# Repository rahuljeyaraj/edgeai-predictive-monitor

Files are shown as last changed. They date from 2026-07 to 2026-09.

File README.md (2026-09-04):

# EdgeAI Predictive Monitor

### Sensors that watch. An AI that decides. A hand that pulls the plug.

A sensor pod that clips onto a machine, learns what *that* machine's healthy
vibration and sound are, and — when it is confident enough that something is
going wrong — **stops the motor**. Not an email. The motor.

Built on the **Arduino UNO Q**: real-time sampling and FFTs on the STM32U585
side, and on the Qualcomm Dragonwing QRB2210 Linux side, on-device PyTorch
training, an Edge Impulse fault classifier, a live dashboard, an MQTT broker,
and the decision to trip.

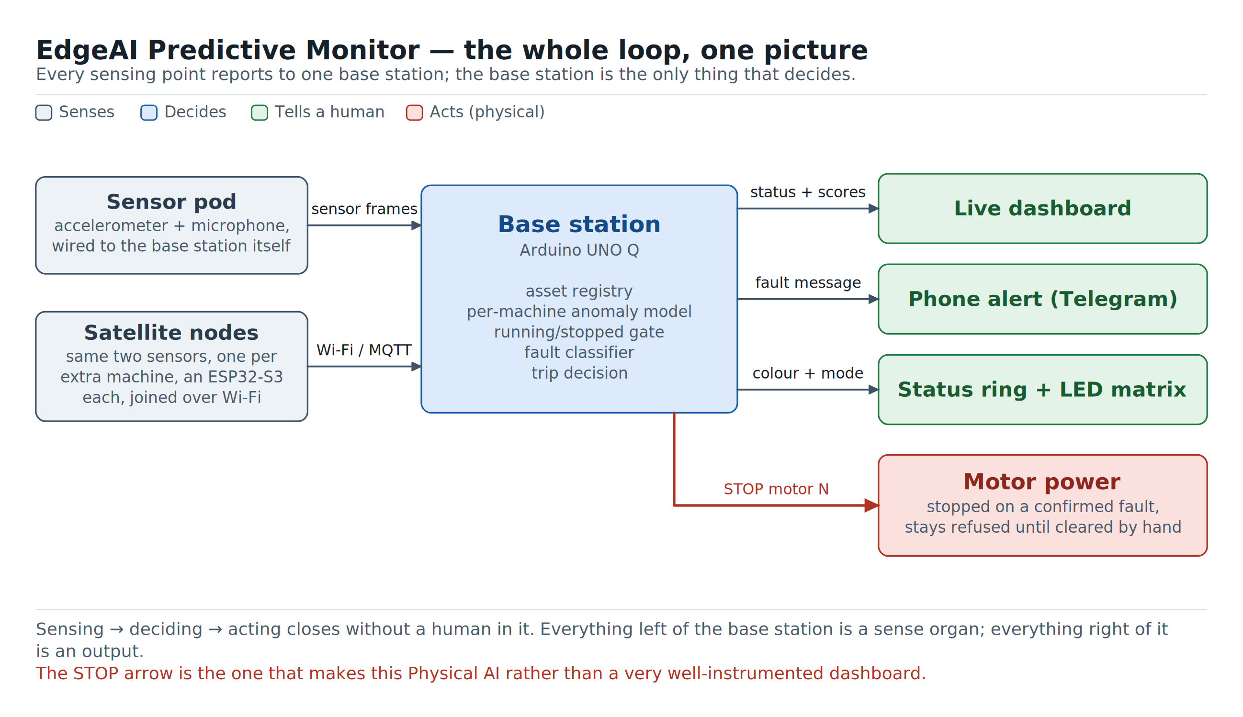
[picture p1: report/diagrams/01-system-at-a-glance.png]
System at a glance


---

## Start here

**[📄 Read the full report →](report/REPORT.md)** — the design, the measured
results, the dead ends, the bill of materials, the schematics, and a
command-by-command build guide. It stands on its own; everything below is a
shortcut into it.

| I want to… | Go to |
|---|---|
| See it running, **with no hardware at all** | [Report → Appendix C.1](report/REPORT.md#appendix-c-build-one-yourself) — 10 minutes, one script |
| Understand what it does and why | [Report → Chapter 1](report/REPORT.md#chapter-1-the-machine-that-never-complains-until-its-too-late) |
| See the part that makes it *Physical AI* | [Report → Chapter 8](report/REPORT.md#chapter-8-the-day-it-stopped-itself) |
| Buy the parts | [Report → Appendix A](report/REPORT.md#appendix-a-bill-of-materials) — ≈ ₹8,115 for one machine |
| Wire it up | [Report → Appendix B](report/REPORT.md#appendix-b-wiring-and-pinout-reference) + [`hardware/kicad/`](hardware/kicad/) |
| Read the code | [Report → Appendix L](report/REPORT.md#appendix-l-reading-the-source) |

## Try it without buying anything

Runs the **real** dashboard on your laptop, fed by a simulator speaking the
**real** wire protocol, replaying **real** captured sensor data. Not a mock —
the registry, feature pipeline, autoencoder, setup flow, thresholds and
classifier are the same code that runs on the board.

```sh
sudo apt-get install -y mosquitto mosquitto-clients   # broker on :1883
sudo systemctl enable --now mosquitto

cd base-station
./start_desktop_dashboard.sh
```

It prints two URLs: the dashboard, and the simulated node's own control page.

## What it does

- **Learns each machine individually.** A short guided setup — name it, measure
  it switched off, run it, train — and that machine has its own model and its
  own thresholds. Training happens on the UNO Q, in seconds. No cloud.
- **Knows when a machine is simply off.** A running/stopped gate calibrated
  against each sensor's own measured noise floor, which turned out to be the
  hardest measurement in the project.
- **Names the fault.** A second model, trained in Edge Impulse and run on-device
  as TFLite, says *bearing* / *imbalance* / *loose mount* — one model per
  machine *type*, so five identical lathes share one.
- **Stops the motor.** On a sustained fault: a visible ten-second countdown with
  a Hold button, then a per-motor stop that latches until a human clears it. If
  the machine keeps turning, it reports the trip as **failed** rather than
  claiming success.
- **Tells someone.** A status ring on the machine, the board's own LED matrix,
  a five-tab live dashboard, and a Telegram alert.
- **Scales over Wi-Fi.** Satellite nodes (XIAO ESP32-S3) join by captive portal
  from a phone — no app, no recompile, no ID to type.

## Repository map

| Path | What's in it |
|---|---|
| [`base-station/`](base-station/) | The UNO Q: Zephyr firmware (`sketch/`), the Linux application (`python/`), host bridges (`host/`), 34 test modules (`tests/`) |
| [`satellite/`](satellite/) | XIAO ESP32-S3 wireless sensor node (PlatformIO) |
| [`motor-driver/`](motor-driver/) | The validation rig: Arduino Uno + CNC Shield firmware, the rig host, and its control page |
| [`hardware/kicad/`](hardware/kicad/) | Three real KiCad schematics, generated from Python |
| [`report/`](report/) | The full report and the generators for every diagram in it |
| [`3d-models/`](3d-models/) | Thirteen printable parts: node enclosures and the validation rig, as 3MF and STL |
| [`docs/BILL_OF_MATERIALS.md`](docs/BILL_OF_MATERIALS.md) | The canonical parts list: what to buy, per build scale, with links |
| [`docs/BUILD_GUIDE.md`](docs/BUILD_GUIDE.md) | Build one yourself, from printed shell to a commissioned machine |
| [`docs/`](docs/) | Design plans and investigation records — the long-form version of the report's appendices |

## Status

| | |
|---|---|
| Sensing, guided setup, per-machine anomaly model | Live-verified on hardware |
| Running/stopped gate with measured baseline | Live-verified on hardware |
| Physical motor trip: stop + latch + confirm | Live-verified on hardware, both directions |
| Dashboard, status ring, LED matrix, Wi-Fi onboarding | Live-verified on hardware |
| Edge Impulse classifier, on-device | Built; trained on 541 real captures from this rig |
| Satellite nodes | Built |
| Telegram alerts | Built and demonstrated; off pending one config value |
| Per-motor relay (cutting power, not just motion) | Not built |

The report's [Chapter 12](report/REPORT.md#chapter-12-proof-not-promises) has
every measured number, and
[Appendix J](report/REPORT.md#appendix-j-test-suite-and-verification-record)
records how each was checked.

## Safety

This is a condition-monitoring system with a protective trip. **It is not a
certified functional-safety system** and must not be used as a guard interlock —
it has no safety integrity level, no redundant channel, and if the base station
loses power nothing trips. It stops *motion*, not power. Every safety function a
machine already has stays exactly where it is. See
[Report → §8.4](report/REPORT.md#chapter-8-the-day-it-stopped-itself).

## Built for

- **Arduino Physical AI Challenge India 2026** — Industrial & Sustainability AI
- **Invent the Future with Arduino UNO Q and App Lab** (Hackster.io) —
  Industrial IoT

## Licence

[MIT](LICENSE).

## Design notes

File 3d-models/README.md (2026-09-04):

# 3D-printed parts

Thirteen printable parts, each supplied as both **3MF** (plated and ready to
slice, with the colour already assigned) and **STL** (plain mesh, if you would
rather plate it yourself).

Print the 3MF unless you have a reason not to. The plates are already oriented
so nothing needs supports.

File names encode the assembly and the filament colour: `a` is the base station,
`b` is the satellite, `c` is the validation rig.

| File | Contains | Colour | Needed for |
|---|---|---|---|
| `a1_base_station_silver` | Shell, `main_front` + `main_back`, snap-fit halves with a front panel cutout | Silver | Base station |
| `a2_base_station_silver` | Mount kit: `left_plate` + `right_plate` backplates, a standoff `leg`, two `stem_connector` pieces joining leg to plate | Silver | Base station |
| `a3_base_station_orange` | Front bezel: `left_rim` + `right_rim` framing the **lens insert** over the status window, plus a separate `foot` standoff | Orange | Base station |
| `b1_satellite_silver` | Shell, same two-piece pattern as `a1`, scaled down for the XIAO ESP32-S3 pod | Silver | Each satellite |
| `b2_satellite_silver` | Mount kit, same as `a2`, scaled for the satellite shell | Silver | Each satellite |
| `b3_satellite_orange` | Front bezel: `left_rim` + `right_rim` plus `foot`. **No lens insert**, since a satellite has no LED matrix | Orange | Each satellite |
| `c1_belt_drive_rig_grey` | Upright L-bracket (`bracket_main`) with a large bearing bore and base mounting holes | Grey | Belt-drive rig |
| `c2_belt_drive_rig_gold` | Three retaining rings: `bearing_ring_1`, `bearing_ring_2`, and an oblong `stepper_ring` | Gold | Belt-drive rig |
| `c3_belt_drive_rig_gold` | Toothed pulley with hex bore, matching hex shaft with pin holes, and a `bearing_holder` hub coupler | Gold | Belt-drive rig |
| `c6_direct_drive_rig_grey` | U-shaped pillow-block `bracket` with a large bearing bore, mounting holes on base and side | Grey | Direct-drive rig |
| `c7_direct_drive_rig_gold` | `bearing_ring_1`, `bearing_ring_2`, `stepper_ring` and the coupling shaft | Gold | Direct-drive rig |
| `c4_fly_wheel_grey` | Rotor disc (`fly_wheel`) with hex hub and a bolt circle | Grey | **Both** rigs |
| `c5_fly_wheel_ring_gold` | Bolt-on ring (`fly_wheel_ring_1`) matching the flywheel's hole pattern | Gold | **Both** rigs |

## What you actually need to print

- **One base station:** `a1`, `a2`, `a3`
- **Each satellite node:** `b1`, `b2`, `b3`
- **Nothing else is needed for a deployment.** The `c` parts are the validation
  rig used to induce and measure faults on the bench.
- **One rig:** pick belt-drive (`c1`, `c2`, `c3`) or direct-drive (`c6`, `c7`),
  then add the shared flywheel (`c4`, `c5`) either way.

## Print settings

| | |
|---|---|
| Material | PLA+ |
| Nozzle | 0.4 mm |
| Layer height | 0.2 mm |
| Infill | 20% for shells and bezels, 40% or more for rig brackets and the flywheel |
| Supports | none; the plates are already oriented |

Colours are what this build used, not a requirement. Any PLA works.

## The flywheel is the fault injector

`c4` + `c5` carry a bolt circle taking M6 × 18 mm bolts. Adding, removing or
moving bolts around that circle produces a repeatable, measurable imbalance,
which is how the labelled fault recordings behind the classifier were made.

## Optional: the embossed wordmark

[`hardware/enclosure-logo/`](../hardware/enclosure-logo/) has emboss-ready SVGs
for the shell faces, sized for the base station and the satellite separately,
with its own README on slicer settings. Engrave recessed at 0.3 to 0.4 mm, not
raised.

Assembly order is in [`docs/BUILD_GUIDE.md`](../docs/BUILD_GUIDE.md); the parts
that go inside these shells are in
[`docs/BILL_OF_MATERIALS.md`](../docs/BILL_OF_MATERIALS.md).

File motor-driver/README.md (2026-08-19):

# Motor Driver: the rotating machine under test

Arduino firmware + browser control page + a host-side rig controller. The Uno
is wired for three stepper motors, but **the rig starts with one installed**,
and the rest are added on the control page — which is the same order a real
factory grows in:

1. A factory sets up its first motor with its own control page —
   `dashboard.html` here, talking straight to the Uno over serial. No AI, no
   base station, no dependency on anything else in this repo.
2. Predictive monitoring gets added later, completely decoupled: the MPU
   vibration sensor watches the motor, but nothing about motor *control*
   changes. The motor's card gains a **PROTECTED** badge naming the asset
   that watches it.
3. More motors are added on the control page as the floor grows. Each one
   installed is announced to the base station as a trip output, so it can be
   mapped to a monitored asset without touching a config file — see
   [../docs/MOTOR_STOP_PLAN.md](../docs/MOTOR_STOP_PLAN.md). That coupling is
   one-way: the base station can stop a motor, never start one.

Design rationale and the capture speed profile live in
[../docs/motor-driver.md](../docs/motor-driver.md).

## Contents
- `src/main.cpp` — Arduino Uno firmware (PlatformIO project, needs
  AccelStepper). Deliberately simple: it applies whatever RPM it's told
  immediately, no ramp logic on the device — see "Why the firmware has no
  ramp" below.
- `dashboard.html` — browser control page: one card per installed motor
  (slider + type-in speed, on/off, sync) over Web Serial. Ramping lives here.
- `motor_driver.py` — the **rig host**. Serves the control page, listens for
  protection trips over MQTT, and can run a scripted capture profile. It does
  *not* hold the Uno's serial port by default — the control page does.
- `start_motor_driver.sh` — starts the rig host (use this, not
  `python3 -m http.server`).
- `fake_uno.py` — runs the rig host against a pseudo-terminal, so the control
  page can be clicked through with no hardware at all.
- `rig_trip_test.py`, `control_page_test.py` — tests; see below.

## Hardware
Arduino Uno + CNC Shield V3 + 3× A4988/DRV8825 drivers in the **X, Y, and Z**
slots. Single 12–24 V supply into the shield terminal.

| Signal  | Motor 1 (X) | Motor 2 (Y) | Motor 3 (Z) | Notes |
|---|---|---|---|---|
| STEP | D2 | D3 | D4 | |
| DIR | D5 | D6 | D7 | |
| ~ENABLE | D8 | D8 | D8 | shared, active LOW |

> **There is no per-motor enable.** One `~ENABLE` line feeds all three driver
> sockets, so `e`/`d` energize or coast *everything*. Stopping a single motor
> means commanding it to 0 RPM. This matters: `e` re-applies whatever speed
> each motor was last told, so anything that stops a motor must send `N 0`
> for it — sending only `d` leaves a stale speed armed, and the next `e`
> (triggered by starting some *other* motor) will spin it back up.

> Set each driver's **Vref (current limit)** before running, and never
> insert/remove a driver with power applied. See the docs file for details.

## Why the firmware has no ramp
Re-flashing this Uno means connecting through WSL, uploading, then
disconnecting again to test over serial — slow enough that firmware changes
should be rare. So `src/main.cpp` only does the minimum: parse a command, set
a motor's speed immediately (`setSpeed()`/`runSpeed()`, no acceleration
curve). Jumping straight to a high RPM can stall a motor, so **all ramping
happens on the host** — `dashboard.html` and `motor_driver.py` both walk the
commanded speed toward the target in small steps before sending it. Tuning or
fixing ramp behavior is now a dashboard/script edit, not a re-upload.

## Build & upload (PlatformIO)
```bash
cd motor-driver
pio run                 # compile-check
pio run -t upload       # flash the Uno (pick the right --upload-port if prompted)
pio device monitor -b 115200   # optional: watch the serial console
```
Confirm `MICROSTEP` in `src/main.cpp` matches the **MSx jumpers** on the
shield (default `1` = no jumpers = full step) before uploading.

## Serial control (115200 baud, newline-terminated)
| Command | Effect | Replies |
|---|---|---|
| `1 <rpm>` | set motor 1 speed (RPM), applied immediately  | silent  |
| `2 <rpm>` | set motor 2 speed (RPM), applied immediately  | silent  |
| `3 <rpm>` | set motor 3 speed (RPM), applied immediately  | silent  |
| `b <rpm>` | set ALL THREE motors, applied immediately | silent  |
| `e` / `d` | energize / coast **all three** drivers | status  |
| `s` | print status | status  |
| `h` | print help | help |

Speed commands answer with nothing on purpose. A status line overflows the
Uno's 64-byte serial TX buffer, which makes `Serial.print()` block and stalls
the step-pulse loop for *all three* motors — during a host ramp that's ~30
stalls/second, and it was audible as every motor stuttering whenever any one
of them changed speed. Poll `s` when you want state.

Negative RPM reverses direction; RPM is clamped to ±1200 (full step).

Example (Arduino Serial Monitor or any terminal) — note the firmware won't
ramp for you, so jumping straight to a high RPM this way can stall a motor:
```
1 60        # motor 1 to 60 RPM (small enough to not need a ramp)
d           # coast to silence
```
For anything faster or bigger, use the dashboard or `motor_driver.py` instead —
they do the ramping.

## Running the rig
```bash
cd motor-driver
./start_motor_driver.sh                          # everything defaulted
./start_motor_driver.sh --mqtt-host uno-q.local  # broker at a different host
./start_motor_driver.sh --mqtt-host ''           # no broker at all
```

Nothing needs to be typed in the normal case. The broker defaults to
`epm-base.local` (the base station's LAN hostname), port **1883**.

> Watch for `ANNOUNCED outputs [1] on epm/motor_rig/outputs`. If the broker
> can't be reached, the rig says so after 6 seconds and tells you nothing was
> announced — because a silent non-connection leaves the base station showing
> whatever a *previous* run left retained, which looks exactly like a bug in
> the dashboard and isn't one.

> After a reboot or a replug, run [`../after_reboot.sh`](../after_reboot.sh)
> first. adb port forwards and the base station's container do not come back
> on their own, and every symptom of that looks like a network fault.

Then open **http://localhost:8000/** in desktop **Chrome or Edge** (Web Serial
isn't supported in Firefox/Safari, or inside sandboxed iframes), click
**Connect**, and pick the Uno's port.

### Who holds the serial port
By default **the control page does**, over Web Serial — and the rig host never
opens it. That is the only arrangement that works on the usual split setup:

> The rig host runs in **WSL**. Chrome and the Uno are on **Windows**.
> `usbipd`-forwarding the Uno into WSL doesn't fix it, it just moves the
> problem — Windows then loses the device and the page has nothing to
> **Connect** to.

So the rig host does the network half (serves the page, holds MQTT, records
trips) and the page does the motor half. When a trip arrives, the rig host
records it and **the page sends the stop**. The header shows `trip via this
page` while that's the arrangement, and turns red with `— not connected` when
the page isn't attached to a port, because protection genuinely is off then.

Pass `--port /dev/ttyACM0` (or `--port auto`) to have the rig host hold the
port instead — for browser-less protection, or a scripted run. `--port auto`
never picks the UNO Q base station, which is also an Arduino-VID device on
`/dev/ttyACM*`; that would write stepper commands into the monitoring board.

`start_motor_driver.sh` passes every argument through to `motor_driver.py`
(`--help` for the full list). It uses `./.venv/bin/python` when that exists,
because `pyserial`/`paho-mqtt` can't be installed system-wide on a PEP 668
host:

```bash
python3 -m venv .venv && ./.venv/bin/pip install pyserial paho-mqtt
```

> **Don't serve this page with `python3 -m http.server`.** It works — you can
> still drive motors — but the page then has nobody to ask which motors are
> installed or whether one has been tripped, and it says so in a banner.

### Motor cards
Each motor card has two independent controls:

- **Speed** — the RPM setting (slider or type-in). Stopping a motor never
  changes this, so starting it again ramps back to the same speed.
- **Run / Stop** — whether that speed is currently applied.

The card also shows a RUNNING/IDLE/STOPPED pill and the currently-commanded
RPM as it ramps toward the setting. **Sync** makes the other motors follow the
first one, and only appears once there are two; changing a follower directly
turns Sync back off. **Stop All** stops everything immediately, skipping the
ramp, and preserves the speed settings.

> Because `~ENABLE` is shared, the page only de-energizes once **all** motors
> are stopped, and it always commands a stopped motor to 0 RPM rather than
> relying on `d`.

> The port opens with a ~2 s Uno reset; wait for the `=== motor-driver ready
> ===` line in the console before driving.

### Adding and removing motors
The rig starts with **one** motor (`--motors` sets the startup set). The empty
slots are `+ Add Motor N` — clicking one installs that motor *and* re-announces
the rig's trip outputs over MQTT, so the new output appears in the base
station's setup live, with nothing restarted. `✕` removes a motor again
(disabled while it's running).

This is the one thing the rig host exists for that a static file server can't
do: the control page has no MQTT client, and the broker is TCP-only, so the
page posts to `motor_driver.py` and *it* publishes the announce.

### Protection status
With `--mqtt-host` set, the page also reads the base station's
`GET /trip_outputs` directly (its API sends `Access-Control-Allow-Origin: *`).
A motor the base station has claimed shows a **PROTECTED · &lt;asset&gt;** badge,
and the header counts how many are protected. Point it elsewhere with
`--base-station-url`; the default is `http://<mqtt-host>:8080`.

### When a trip lands
A trip turns the motor's card red, sets the pill to **TRIPPED**, locks the run
switch, and names the asset that faulted. Only **Reset & re-arm** brings it
back — a trip is sticky until a human clears it, enforced in
`Rig.motor()` and not merely promised.

## Scripted capture runs
```bash
./start_motor_driver.sh --profile --motors 1,2,3   # needs the port; autodetects it
```
Runs baseline → speed sweep → injected fault (the first installed motor steps
up, the rest are held) so the captured vibration maps to labels, then exits.
Without `--profile` the rig host just idles with the control page served and
the trip listener armed.

> Don't expect to observe a live trip during `--profile`: its fixed timing
> races the base station's variable fault-detection timing, and the profile
> has ended before the trip lands (`docs/progress4.md`).

## Tests
```bash
python3 rig_trip_test.py                                   # no hardware needed
../base-station/python/.venv/bin/python control_page_test.py   # needs playwright
```
`rig_trip_test.py` pins the trip's exact serial bytes and the runtime-editable
output set. `control_page_test.py` drives `dashboard.html` in a real headless
Chromium against a real `ControlServer` and a stand-in base station.

## Clicking through it with no hardware
`fake_uno.py` runs the rig host against a pseudo-terminal instead of a real
Uno. Everything except the motors is real — same page, same control server,
same MQTT trip listener:

```bash
python3 fake_uno.py                        # open http://localhost:8000/
python3 fake_uno.py --mqtt-host <uno-q>    # against a real base station
python3 fake_uno.py --mqtt-host <uno-q> --trip-after 20   # trip motor 1 at 20 s
```

`--trip-after` publishes the base station's exact `MOTOR_STOP` bytes, so the
trip arrives through the real listener — the way to see the tripped card and
**Reset & re-arm** without waiting for a genuine fault. Web Serial will fail
to find a port; ignore it, none of the above needs it.

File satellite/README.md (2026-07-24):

# satellite — ESP32S3 satellite node firmware

PlatformIO/Arduino firmware for the Seeed Studio XIAO ESP32S3, one of
potentially several **satellite** vibration/audio sensing nodes for the
EdgeAI Predictive Monitor. It ports [`base-station/sketch`](../base-station/sketch)
(the Zephyr firmware for the UNO Q's onboard STM32U585) to this board,
mirroring every functional piece — KX134 accelerometer, INMP441 I2S
microphone, WS2812 status ring, per-channel FFT, fused publish cadence —
except the transport: the base station talks SPI to its MPU over a wired
point-to-point link; this node talks WiFi + MQTT instead, since it isn't
physically attached to the UNO Q
([docs/SENSOR_TELEMETRY_FRAME_PLAN.md](../docs/SENSOR_TELEMETRY_FRAME_PLAN.md)
S6).

There is no LED matrix on this node (no MQTT command type exists for one,
and the existing satellite tooling doesn't model one either — see
[`python/tools/satellite_node_sim.py`](../base-station/python/tools/satellite_node_sim.py)).

## Wire format

Telemetry (`epm/<node_id>/data`) is the **same generic section-list frame**
the base station's own SPI link sends
([`base-station/telemetry_schema.json`](../base-station/telemetry_schema.json),
[docs/SENSOR_TELEMETRY_FRAME_PLAN.md](../docs/SENSOR_TELEMETRY_FRAME_PLAN.md)
S3/S6): `[num_sections u8]` then, per channel, a
`[source_id][channel_id][data_kind][section_len]` header followed by either
a SPECTRUM body (`fs`/`fft_size`/`bin_count`/dense float32 bins) or, for one
trailing SCALAR_SET section, a `count`/id-array/value-array body. Published
as the raw MQTT message body with **no extra envelope** — MQTT already
frames and delivers each message, so a second TYPE byte would be redundant.
This node emits one SPECTRUM section per enabled per-axis channel (`mic`,
`accel_x`, `accel_y`, `accel_z` — the combined `accel` channel was retired
once the base station's own model moved to per-axis, see
`pipeline/features.py`) plus one SCALAR_SET section carrying that same
channel set's `rms`/`kurtosis`/`std`/`peak`/`crest_factor`/`skewness` tiles
(`frame_codec/spectrum_codec.h`, `struct spectrum_channel`/`struct
scalar_entry` + `telemetry_build_frame()`) — `pipeline/features.py`'s
`build_feature_vector()` rejects a frame outright if any live channel is
missing its full 6-scalar tile. Wire constants (`TELEM_SOURCE_SATELLITE`, `TELEM_CHANNEL_MIC`, …)
live in `include/frame_codec/telemetry_schema.h`, generated (not hand-edited)
by
[`python/tools/gen_telemetry_schema.py`](../base-station/python/tools/gen_telemetry_schema.py)
from the same schema file the base station and MPU parser are generated
from, so the three sides can't drift. This replaced an earlier fixed
`spectrum_fused_payload_header` struct (itself replacing a still-earlier
JSON envelope of top-N peaks per channel) once the base station's own wire
format moved to this generic section-list shape.

The command direction (`epm/<node_id>/cmd`, STATUS_LED) keeps its own lean
`[TYPE: 1B][display_rgb_payload]` envelope (`frame_codec/wire_protocol.h`) —
unaffected by the telemetry-format change above.

The wire shape matches
[`python/tools/satellite_node_sim.py`](../base-station/python/tools/satellite_node_sim.py)
and
[`python/ingestion/mqtt_subscriber.py`](../base-station/python/ingestion/mqtt_subscriber.py)
field-for-field, so a real node and the simulator are interchangeable from
the dashboard's point of view. FFT window sizes (1024 per channel → 512
native bins, pooled to `MODEL_SPECTRUM_BINS` = 128 for the wire — a node's
actual per-channel bin count is committed dynamically from its first frame
by
[`python/pipeline/manager.py`](../base-station/python/pipeline/manager.py),
not a fixed global table) and the publish cadence (200ms) are set in
`include/app_config.h`.

## Hardware / wiring

XIAO ESP32S3 breaks out 11 GPIOs (D0–D10). Full pin rationale is in
`include/board_pins.h`; summary:

| Signal | Pin | Notes |
|---|---|---|
| KX134 SPI SCK | D8 | hardware SPI default |
| KX134 SPI MISO | D9 | hardware SPI default |
| KX134 SPI MOSI | D10 | hardware SPI default |
| KX134 CS | D3 | software chip-select |
| KX134 INT1 (BFI) | D2 | buffer-full interrupt |
| INMP441 WS/LRCLK | D0 | |
| INMP441 BCLK | D1 | |
| INMP441 SD (data in) | D4 | |
| WS2812 ring DIN | D5 | 8-pixel ring, same product as the base station's |

`LED_BUILTIN` (GPIO21, onboard) is the heartbeat indicator — independent
of the WS2812 ring, mirroring the base station sketch's own onboard-LED
heartbeat.

## Configuration

WiFi/MQTT settings live in `include/app_config.h` as overridable
`#define`s (`WIFI_SSID`, `WIFI_PASSWORD`, `MQTT_BROKER_HOST`,
`MQTT_BROKER_PORT`). Defaults assume the base station hosts its own AP
(SSID `EPM-BaseStation`) and runs the Mosquitto broker at `10.42.0.1` —
confirm these against the actual base-station deployment before flashing.
**`WIFI_PASSWORD` has no documented value and must be set before
flashing**, either by editing `app_config.h` directly or overriding via
`platformio.ini`'s `build_flags` (`-D WIFI_PASSWORD=\"...\"`).

Node identity is derived automatically from the ESP32's WiFi MAC address
(last 6 hex chars, lowercase) — no per-device flashing-time configuration.

## Build / flash

```sh
cd satellite
pio run                # build
pio run -t upload      # flash over USB (native USB CDC, no separate bridge chip)
pio device monitor     # serial log console (115200 baud)
```

After editing `base-station/telemetry_schema.json`, regenerate every
generated side (including this firmware's
`include/frame_codec/telemetry_schema.h`) with:

```sh
python3 base-station/python/tools/gen_telemetry_schema.py
```

## What's *not* hardware-verified

Everything in `base-station/sketch` was brought up and tuned against real
STM32U585 hardware (documented empirically in that codebase's comments —
e.g. the KX134 SPI pin-routing finding, the I2S DMA-width bug). This port
compiles clean (`pio run`, zero warnings under `-Wall -Wextra`) but **has
not been run against a physical XIAO ESP32S3 + KX134 + INMP441 + WS2812
ring**. Specifically flagged as assumptions, not findings, in the source
comments:

- `src/drivers/mic_i2s.cpp`: sample rate (48kHz) and the INMP441's
  32-bit-slot right-shift (`>> 8`) — reasonable per-datasheet defaults,
  not bench-confirmed.
- `src/threads/accel_sampler_task.cpp`: `ACCEL_SAMPLER_READ_CHUNK_FRAMES`
  (64) — carried over from the base station sketch's own tuned result, not
  re-derived from a characterization run on this board.
- `include/board_pins.h`: the D0–D5 assignments are conflict-free on
  paper (verified against the XIAO ESP32S3 variant's actual
  `pins_arduino.h`) but unverified against a real wiring harness.

Bring-up on real hardware should revisit these the same way
`base-station/sketch`'s own comments document its STM32 tuning history.
The telemetry wire format itself (this doc's "Wire format" section) is
verified by construction — generated from the same schema the base
station and MPU parser share — but has not yet been exercised by a real
publish against a running `mqtt_subscriber.py`; do that once hardware is
available, the same way `satellite_node_sim.py` already exercises it in
simulation.

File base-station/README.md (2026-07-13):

# 📳 edgeai-predictive-monitor-base-station

On-device predictive maintenance for rotating machinery

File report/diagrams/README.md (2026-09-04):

# Report diagrams

Block diagrams for `REPORT.md`. No graphviz or mermaid on this machine, so
they're composed in plain Python and rasterised with
[cairosvg](https://cairosvg.org/), via `gen/diagram_lib.py`.

## One-time setup

```sh
cd report/diagrams
python3 -m venv .venv
.venv/bin/pip install cairosvg
```

## Regenerate

Edit the matching script in `gen/`, then run it from inside `gen/`:

```sh
cd report/diagrams/gen
../.venv/bin/python d5_full_architecture.py
```

Each script writes both the `.svg` and the `.png` one level up. `REPORT.md`
embeds the PNGs — Pandoc's PDF pipeline needs raster, not raw SVG.

Regenerate everything:

```sh
cd report/diagrams/gen
for f in d*.py; do ../.venv/bin/python "$f"; done
```

| Script | Output | Used in |
|---|---|---|
| `gen/d1_overview.py` | `01-system-at-a-glance.png` | Ch. 1 |
| `gen/d2_basestation_wiring.py` | `02-base-station-wiring.png` | Ch. 3 |
| `gen/d3_satellite_wiring.py` | `03-satellite-node-wiring.png` | Ch. 4 |
| `gen/d4_feature_pipeline.py` | `04-feature-pipeline.png` | Ch. 5 |
| `gen/d5_full_architecture.py` | `05-full-architecture.png` | Ch. 9 |
| `gen/d6_asset_lifecycle.py` | `06-asset-lifecycle.png` | Ch. 8 |
| `gen/d7_trip_sequence.py` | `07-trip-sequence.png` | Ch. 7 |
| `gen/d8_dashboard_anatomy.py` | `08-dashboard-anatomy.png` | Ch. 9 |
| `gen/d9_onboarding.py` | `09-onboarding.png` | Ch. 4 |
| `gen/d10_setup_flow.py` | `10-setup-flow.png` | Ch. 5 |
| `gen/d11_edge_impulse_flow.py` | `11-edge-impulse-flow.png` | Ch. 7 |
| `gen/d12_software_architecture.py` | `12-software-architecture.png` | Ch. 10 |
| `gen/d13_tab_map.py` | `13-dashboard-tabs.png` | Ch. 9 |
| `gen/d14_two_brains.py` | `14-two-brains.png` | Ch. 2 |
| `gen/d15_code_structure.py` | `15a`…`15f` (six figures) | S5 (code structure) |
| `gen/d16_system_overview.py` | `16-system-overview.png` | Hackster article, sec. 2.2 |
| `gen/d17_system_overview_alt.py` | `17-system-overview-alt.png` | variant B of 16, not placed yet |
| `gen/d18_status_light.py` | `18-status-light.gif` + `.png` | Hackster article, sec. 2.11 |

`gen/d18_status_light.py` is the other exception: it is raster, not SVG, and
it does not use `diagram_lib` or cairosvg at all. It draws with Pillow +
numpy and writes an **animated GIF**, because the thing being documented is
the blink pattern — a still frame cannot tell a WARNING strobe from a PAUSED
const, both being the same amber. It also writes a matching still PNG (every
ring lit) for print, where a GIF cannot animate. Its colours, modes and
periods are read from `registry/status_color.py` and
`satellite/src/threads/transport_task.cpp`; its blink maths is copied from
the two ring drivers. It needs `numpy` in the venv:
`.venv/bin/pip install numpy`.

`gen/d15_code_structure.py` is the exception to one-script-one-diagram: it
emits six figures (`15a-tiers`, `15b-wire-format`, `15c-linux-packages`,
`15d-frame-journey`, `15e-trip-path`, `15f-setup-steps`) so they share one
set of sizing constants. It is also the only script that overrides `save()`'s
default `scale=2.2`, passing `scale=3.2` (~307 dpi).

Those figures are sized for **Word**, not for this repo's PDF, and that drives
three rules the other scripts do not follow:

* **Canvas width stays near 900 px.** Legibility on paper is set by the ratio
  of font size to canvas width, not by pixel count. At 900 px wide, 13 pt body
  text lands at ~8.5 pt when the figure is placed at the page's full ~6.5 in
  text width. The first draft of these was 1860 px wide and the same text came
  out under 4 pt.
* **Height stays under ~1.25x the width**, so a figure can sit at full width
  without running past the bottom of the page. Being shrunk to fit is what
  destroys the font size, so a tall figure defeats the rule above.
* **Split rather than cram.** Anything that needed a long edge, a crossing, or
  a three-bend detour became its own figure instead. Every edge in the six is
  straight or has one shared riser.
* **Structure, not call traces.** `15c` and `15d` replaced a pair of figures
  that drew call sites and line numbers: accurate, but unreadable to anyone
  not already holding the source. `15c` answers "where does the code live",
  `15d` answers "what runs when", and both name modules rather than lines.

Note the chapter column moved when the report gained a dedicated Edge Impulse
chapter — `06-asset-lifecycle` and `08-dashboard-anatomy` are both Ch. 9 now,
and `07-trip-sequence` is Ch. 8.

## What `diagram_lib.py` enforces

The library exists so individual scripts can't reintroduce the defects the first
generation of these diagrams had:

* **Framed layout.** A `Canvas` reserves a title band and a footnote band, and
  content is laid out between them — so a caption can never end up sitting on
  top of an arrowhead.
* **Measured text.** `text_width()` estimates rendered width, so legend chips,
  edge labels and group labels are sized to their content. Under-measuring is
  what let a group's dashed border cut straight through its own title.
* **Labels beside lines, not on them.** `link()` hangs an edge label above a
  horizontal segment or alongside a vertical one, so the line and its
  arrowhead stay visible — a backplate centred on a short segment used to
  swallow the arrow whole. `label_side` and `label_seg` override the side and
  the segment when the default lands on something.
* **Orthogonal routing.** `link()` takes explicit points and `elbow()` jogs on
  one axis. Diagonals through a block diagram read as sketchy, and were the main
  source of label collisions.
* **A bend has to mean something.** This one the scripts have to keep, because
  `link()` takes the points it's given. Two boxes joined by one edge sit on the
  *same* centre line, so the edge is straight: a jog only because a box was
  placed at a round number reads as a detour the data actually takes, and a page
  of them reads as a staircase. When one box fans out to several — which cannot
  all be level with it — the branches leave from one shared point and climb one
  shared riser, so it reads as one fan (see `d5`, `d4`, `d7`). Draw an
  odd-coloured branch first, so the neutral ones overdraw the shared trunk and
  it doesn't pick up their colour.
* **One palette, one meaning.** `ROLES`: slate = senses, blue = decides,
  red = acts physically, green = tells a human, amber = degraded, ghost = derived
  or not-a-decision. The reader learns the colour code once and it holds across
  all nine diagrams.

## Editing in a UI instead

Open a `.svg` in Inkscape or Figma and edit it there. If you do, export a
matching `.png` by hand — and don't rerun the Python script afterwards, it will
silently overwrite the manual edit.

## The `*-schematic-kicad.png` files

`02b-base-station-schematic-kicad.png`, `03b-satellite-node-schematic-kicad.png`
and `06-motor-driver-rig-schematic-kicad.png` are a different animal: real KiCad
schematics — actual `.kicad_sch` files with symbols and nets, openable in KiCad —
not hand-drawn blocks. Source lives in `hardware/kicad/`, not in this folder's
`gen/`. They're copied here as PNGs so `REPORT.md`'s image paths stay relative to
one folder. Regenerate from `hardware/kicad/` and recopy; don't edit these PNGs.

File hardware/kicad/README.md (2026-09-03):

# KiCad schematics

Real KiCad 9 schematics (symbols + nets, not block diagrams) for the three
wiring diagrams in `report/REPORT.md`: the base station, a satellite node,
and the motor-driver rig. Pinouts are transcribed from `REPORT.md`
Chapter 2.3 / 3.3 / Appendix B — if a pin changes there, regenerate here.

| Script | Output | Report location |
|---|---|---|
| `base_station.py` | `base_station.kicad_pro` + `.kicad_sch` | Chapter 2.3 / Appendix B.1 |
| `satellite_node.py` | `satellite_node.kicad_pro` + `.kicad_sch` | Chapter 3.3 / Appendix B.2 |
| `motor_driver_rig.py` | `motor_driver_rig.kicad_pro` + `.kicad_sch` | Chapter 5 / Appendix B.3 |

Each script writes a matching `.kicad_pro` (minimal -- KiCad backfills its
defaults on first open; `sheets` points at the `.kicad_sch` root UUID) so
the pair opens as a self-contained *project*, not a loose sheet that makes
KiCad prompt to create one. Each `.kicad_sch` also opens directly in KiCad
(Eeschema) on its own. Every part -- UNO Q,
XIAO ESP32S3, KX134, INMP441, WS2812 ring, A4988/DRV8825, NEMA-17 -- is a
generated generic box symbol, since none of these breakout boards have
official KiCad library parts. Connections are drawn as short pin stubs +
matching net labels (not long point-to-point wires), which is what keeps the
layout readable.

**Controller pins are named the way the board names them**, not by MCU
function or port: `D13`/`A4`/`SCL` on the UNO Q, `D0`-`D10` on the XIAO,
`D2`-`D8` on the Uno under the CNC shield. That is what is printed on the
silkscreen and what you probe, so it is what the symbol says; the signal's
role lives in the net label instead (`SPI_SCK`, `MIC_SD`) -- the pin number
isn't repeated there since the symbol pin already shows it. Sensor and
driver parts keep their datasheet pin names -- those boards really are
labelled `SCK`/`SDO`/`STEP`. Port-level mapping for the UNO Q comes from the
board's own `gpio-map` in `zephyr/boards/arduino/uno_q/
arduino_r3_connector.dtsi`; for the XIAO, from
`satellite/include/board_pins.h`.

## Regenerating

The `.kicad_sch` files are generated by `gen.py` (the symbol/schematic
writer) plus one script per diagram. To change a pin or add a part, edit
the relevant script and rerun it:

```sh
python3 base_station.py        # writes base_station.kicad_sch
```

Text sizes (headings, pin names, net labels) are centralized as constants at
the top of `gen.py` (`PROP_SIZE`, `PIN_TEXT_SIZE`, `LABEL_SIZE`) -- they're
sized well above KiCad's 1.27mm default so the schematic stays legible after
being pasted into a Word doc and shrunk to a page column. Row placement for
stacked parts (the sensor column next to each controller) goes through
`stack_column()`, which spaces rows using each part's actual box height plus
its caption text, rather than fixed y-coordinates -- if you bump the size
constants further, placement adjusts on its own instead of needing every
`.py` script's row positions hand-tuned again.

## Exporting images

```sh
kicad-cli sch export svg --exclude-drawing-sheet base_station.kicad_sch -o .
```

`--exclude-drawing-sheet` drops the sheet border, ruler ticks and title
block, so the SVG holds only the circuit -- nothing to mask out at crop
time, and the crop stays correct at any raster scale.

PNG export needs a rasterizer; `kicad-cli` doesn't do SVG->PNG directly.
This machine has no system rasterizer (no `rsvg-convert`/`pdftoppm`), so a
local venv with `cairosvg` was used instead (`libcairo2` is already a
system library here, so no sudo was needed for that part):

```sh
python3 -m venv .venv && .venv/bin/pip install cairosvg pillow numpy
.venv/bin/python -c "import cairosvg; cairosvg.svg2png(url='base_station.svg', write_to='base_station.png', scale=5.0)"
```

`scale=5.0` (~3600-3900px wide) is deliberate headroom: the report's host
(Hackster) re-runs every inline image through an imgix proxy with
`auto=compress`, so thin schematic lines and pin labels need to go in at
2-3x their rendered width to survive that pass legibly. It also feeds the
sibling `.jpg` (quality 92) exported from the same crop. The vector-perfect
route for anyone who needs to zoom is the per-sheet `.pdf` -- attach those
as raw files, they bypass the image CDN.

The report PNGs are cropped copies -- since the drawing sheet is already
excluded from the SVG, the crop is just the ink bounding box: flatten any
alpha onto the sheet background `(245, 244, 239)` for a true PNG-24 (no
alpha channel), scan for ink (`L < 200`; the cream background sits at ~244
and never trips), pad 42px. No corner mask needed any more.

```python
im = Image.open("base_station.png")
bg = Image.new("RGB", im.size, (245, 244, 239))
bg.paste(im, mask=im.split()[-1] if im.mode == "RGBA" else None)
a = np.array(bg.convert("L"))
ys, xs = np.where(a < 200)
PAD = 42
bg.crop((max(xs.min()-PAD, 0), max(ys.min()-PAD, 0),
         min(xs.max()+PAD, bg.width), min(ys.max()+PAD, bg.height))).save(out)
```

Report copies live in `report/diagrams/` as `02b-`, `03b-`, and
`06-*-schematic-kicad.{png,jpg}`, kept separate from the report's own
hand-built block diagrams.

## Uploading to Hackster

`make_bundles.py` zips each `.kicad_pro` + `.kicad_sch` + `.pdf` into
`dist/<board>-kicad.zip`, plus an all-three `dist/edgeai-schematics-kicad.zip`.
Attach the zip(s) under the project's **Attachments** -- Hackster serves
attachments as raw downloads, so the KiCad files and PDFs arrive intact
(the image CDN only touches inline Story images). `dist/` is git-ignored;
regenerate it any time with `python3 make_bundles.py`.

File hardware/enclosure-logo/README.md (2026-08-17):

# Enclosure logo (emboss-ready)

Vector wordmark for embossing/engraving on the 3D-printed base station and
satellite shells. Matches the dashboard topbar logo
([base-station/python/frontend/index.html](../../base-station/python/frontend/index.html))
but with every glyph converted to a real path (no font dependency at
print/slice time) and single solid black fill, since embossing tools
extrude solid shapes, not text.

## Files

| File | Use | Notes |
|---|---|---|
| `edgeai-logo-emboss-base-station-60mm.svg` | Base station shell | Full "EdgeAI / PREDICTIVE MONITOR" lockup, 60mm wide |
| `edgeai-logo-emboss-satellite-32mm.svg` | Satellite shell | "EdgeAI" only, 32mm wide — the subtitle text was dropped here because it engraves too small to read (see below) |
| `edgeai-logo-emboss-master.svg` | Source / rescaling | Full lockup at natural design scale (1 unit = 1mm) |

All three are vector — open any of them in your slicer/CAD tool and scale
to whatever actually fits your shell face; the mm sizes above are just
starting points, not a size you're locked into.

The "PREDICTIVE MONITOR" subtitle is set in **bold**, not the dashboard's
regular weight, and larger relative to "EdgeAI" than the on-screen version
— the dashboard sizing was tuned for a screen, not a 0.4mm engraving
groove, and thin regular-weight strokes at that scale don't hold.

## Why the satellite mark drops the subtitle

At 32mm total width even the bold subtitle would print under 3mm cap
height — too small for a 0.4mm-nozzle FDM print to hold individual
letterforms (`M`/`O`/`N` strokes merge into blobs below that). The base
station's 60mm version keeps the subtitle at ~4mm cap height, comfortably
legible.

## Using with a slicer (PrusaSlicer / OrcaSlicer / Bambu Studio)

1. Load your shell STL, then use the slicer's "Emboss"/SVG tool and import
   the relevant file above.
2. **Engrave (recessed), not raised — depth 0.3–0.4mm.** A raised stroke
   this thin can snap off in handling, and recessed text needs no
   support/overhang. Optionally paint-fill the recess afterward (rub
   paint or a marker in, wipe the surface clean) for contrast.
3. Position on the face, reduce size only if needed — don't scale below
   the mm width used to generate the file or the strokes will thin
   further.

## Regenerating / editing the text

`gen_logo.py` builds all three files from DejaVu Sans Bold/Regular (close
metrical substitutes for the dashboard's Arial). Edit the strings in
`build_svg()` and rerun:

```
pip install fonttools
python3 gen_logo.py .
```

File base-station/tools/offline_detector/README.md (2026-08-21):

# Offline detector

Tells you whether an "everything went Offline" event on the dashboard was the
**app** or the **link**. Those look identical on screen and need opposite
fixes, which is why this exists.

## Why the ambiguity is real

`OFFLINE` is computed entirely in the browser — `frontend/app.js`'s
`OFFLINE_AFTER_S = 10`, applied to `last_seen` staleness. Nothing server-side
ever sets it. So a node reads Offline for either of two reasons:

- the app genuinely stopped seeing that node, **or**
- the browser could not fetch fresh data within 10s.

The second one paints the *entire* fleet Offline at once, `base_station`
included — and `base_station` arrives over SPI and never touches MQTT, so a
whole-fleet flip is itself a hint that the transport to the browser is at
fault rather than any per-node path.

## Use it

```sh
./offline_probe.sh 120          # 120s, three lanes, one verdict
BOARD_IP=192.168.1.42 ./offline_probe.sh
```

Three lanes run in the same window:

| lane | what it asks | crosses WiFi? |
|---|---|---|
| BOARD | `GET /nodes` from inside the UNO Q via `adb shell` | no |
| LAN | the same GET from the **Windows** host | yes |
| PING | PC→board vs PC→router | yes |

Board clean + LAN dirty ⇒ the link. Board dirty ⇒ the app — debug ingest, and
check the `frames_ok` / `arm_errors` / `on_frame_errors` deltas it prints.

"Board dirty" means **`base_station`** went stale, not that any node did. That
distinction is the whole game: only `base_station` arrives over SPI, so it is
the one node whose staleness cannot be WiFi. The other twelve all cross the
air — the two real satellites once, and the ten sim nodes from the dev PC,
over the very link the PING lane is measuring. A max() across all thirteen
therefore reports "the app went stale" for what is really a WiFi outage.
`frames_ok` does not rescue it either: that counter is the SPI lane only, so
it climbs happily through a window in which every MQTT node has gone quiet.

## Stage 2: `node_isolate.sh` — which node, and missing or merely late?

```sh
./node_isolate.sh 120
```

Runs two lanes side by side **on the board**, so neither crosses WiFi to
reach you:

| lane | what it asks |
|---|---|
| `nodes.csv` | what the app believes — `GET /nodes`, per node, 1/s |
| `broker.csv` | what actually arrived — every `epm/<node>/data` message |

Both subscribe to the same broker on the same box, so at any tick the newest
message the subscriber has seen is the newest the app could possibly have
applied. The difference — the **app lag** column — is time the frame spent
inside the app rather than on the air. Stale node with near-zero lag ⇒ the
frames never came. Stale node with seconds of lag ⇒ they came and the app sat
on them.

Read `app lag`, not `worst gap`: a node that delivers one short burst and is
otherwise silent scores a tiny gap, because the silence sits *outside* its
messages rather than between them. Two real satellites scored 2.3s and 20.8s
that way on 10 and 20 messages in 120s.

Caveat: the broker lane takes a full copy of every telemetry payload over
loopback, so it is not free on a board already near its ingest ceiling.

## Two traps that cost a session

- **The dashboard is on port 8080, not 8000.** `curl` against a closed port
  returns in ~35ms with rc=7 — which reads exactly like a healthy fast
  response if you only look at elapsed time. Always check the status code.
- **Run the LAN lane from Windows, not WSL2.** WSL2 does not share the
  browser's route to the board; measured 6/6 WSL timeouts in a window where
  Windows got 2/6 through. Same reason `adb forward` must never be used to
  judge reachability.

## `load_amplifier.sh` — read the caveat

Raises the failure rate on demand (N concurrent pollers) so you can exercise a
suspected fix without waiting. **It does not reproduce the reported bug**: the
real complaint occurs with a single dashboard tab, while this makes an
*overloaded* link fail, possibly by a different mechanism. `offline_probe.sh`
is the instrument to trust. Calibration numbers are in the script header.

## Files

| file | runs on |
|---|---|
| `offline_probe.sh` | WSL — orchestrates all three lanes |
| `node_isolate.sh` | WSL — orchestrates stage 2 |
| `node_probe.py` | pushed to the UNO Q — per-node `last_seen` ages |
| `board_lanes.sh` | pushed to the UNO Q — runs the app and broker lanes |
| `isolate_summary.py` | WSL — merges stage 2 into the per-node table |
| `board_probe.py` | pushed to the UNO Q, run via `adb shell python3` |
| `lan_probe.ps1` | Windows host, via `powershell.exe` |
| `summarize.py` | WSL — merges the lanes into one verdict |
| `load_amplifier.sh` | WSL — optional, see caveat above |

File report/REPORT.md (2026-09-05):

<!-- Placeholder convention: [PHOTO: ...] [SCREENSHOT: ...] [VIDEO STILL: ...]
     [FILL IN: ...] marks a real value (name, date, receipt figure) not yet
     known. Every diagram referenced here is real and lives in diagrams/. -->

# EdgeAI Predictive Monitor

### Sensors that watch. An AI that decides. A hand that pulls the plug.

| | |
|---|---|
| **Built on** | Arduino UNO Q — Qualcomm Dragonwing QRB2210 (Debian Linux) + STM32U585 (Zephyr) |
| **Entered in** | Arduino Physical AI Challenge India 2026 — *Industrial & Sustainability AI*<br>Invent the Future with Arduino UNO Q and App Lab (Hackster.io) — *Industrial IoT* |
| **AI stack** | PyTorch on-device (anomaly) · Edge Impulse (fault classifier, TFLite on-device) |
| **Team / author** | Rahul Jeyaraj |
| **Date** | September 2026 |
| **Source** | [github.com/rahuljeyaraj/edgeai-predictive-monitor](https://github.com/rahuljeyaraj/edgeai-predictive-monitor) — open source under the MIT licence |
| **Demo video** | [youtube.com/watch?v=8h05_KkEtwQ](https://www.youtube.com/watch?v=8h05_KkEtwQ) — 12:53, the full walkthrough |

> **[PHOTO: cover image — the assembled base station clipped to the test rig, machine running, status ring lit, dashboard visible on a laptop behind it]**

---

## Table of contents

**Part I — The system**

| | Chapter | What's in it |
|---|---|---|
| 1 | [The machine that never complains until it's too late](#chapter-1-the-machine-that-never-complains-until-its-too-late) | The problem · what the system does · honest scorecard · what makes this Physical AI |
| 2 | [Why the Arduino UNO Q](#chapter-2-why-the-arduino-uno-q) | Two brains, one board · the four jobs it does at once · what App Lab does for it · what this would cost without the board |
| 3 | [Building the base station](#chapter-3-building-the-base-station) | One board, one machine · what gets wired where · first light |
| 4 | [Growing the fleet](#chapter-4-growing-the-fleet) | Satellite nodes · onboarding one from a phone · one wire format for every node |

**Part II — The intelligence**

| | Chapter | What's in it |
|---|---|---|
| 5 | [Teaching it what normal feels like](#chapter-5-teaching-it-what-normal-feels-like) | The six-step guided setup · the feature vector · the autoencoder · thresholds · more than one kind of normal |
| 6 | [Naming the fault](#chapter-6-naming-the-fault) | The supervised classifier · one model per machine type · what it is and is not allowed to do |
| 7 | [Training the classifier with Edge Impulse](#chapter-7-training-the-classifier-with-edge-impulse) | The full round trip: record, link, upload, train, fetch, run — every step, and where the line was drawn |
| 8 | [The day it stopped itself](#chapter-8-the-day-it-stopped-itself) | The trip chain · why it is delayed · why a failed trip is never reported as a trip · what this is not · the calibration that made it trustworthy |

**Part III — The human interface**

| | Chapter | What's in it |
|---|---|---|
| 9 | [What the operator actually sees](#chapter-9-what-the-operator-actually-sees) | Every status an asset can hold · the trip banner · all five tabs in detail · the light on the machine · the phone alert |

**Part IV — The engineering**

| | Chapter | What's in it |
|---|---|---|
| 10 | [Under the hood](#chapter-10-under-the-hood) | The software architecture layer by layer · one frame's journey · the two chip-to-chip links · what runs as what · what is stored where · what makes it smooth, and the throughput ceiling that is left |
| 11 | [Why we built it this way](#chapter-11-why-we-built-it-this-way) | Ten decisions, the alternatives, and what each one cost |
| 12 | [Proof, not promises](#chapter-12-proof-not-promises) | Measured results · a real setup run · the measured cost of multi-condition training · the satellite on real hardware · known limitations · the status ledger |
| 13 | [What's next](#chapter-13-whats-next) | The near-term roadmap, in build order |

**Appendices**

| | Appendix | What's in it |
|---|---|---|
| A | [Bill of materials](#appendix-a-bill-of-materials) | Every part, every subsystem, with Robu.in links and prices — plus the software and tools list. The **only** parts list in this document |
| B | [Wiring and pinout reference](#appendix-b-wiring-and-pinout-reference) | Every pin on all three boards, plus the real KiCad schematics — the **only** wiring detail in this document |
| C | [Build one yourself](#appendix-c-build-one-yourself) | Command-by-command reproduction: base station, satellite, motor rig, and two paths that need no hardware at all |
| D | [Sensor selection rationale](#appendix-d-sensor-selection-rationale) | Why the KX134 beat both the cheaper and the more expensive options |
| E | [Network and transport selection rationale](#appendix-e-network-and-transport-selection-rationale) | BLE beacon vs BLE GATT vs Wi-Fi, and why the third won |
| F | [Wire protocol specification](#appendix-f-wire-protocol-specification) | Message types, both framings, QoS, and the schema that keeps three codebases in step |
| G | [Sensor configuration envelope](#appendix-g-sensor-configuration-envelope) | How fast and how finely this hardware can actually be pushed, what we run at, and why |
| H | [Motor-state gate calibration](#appendix-h-motor-state-gate-calibration) | The full investigation: three wrong layers, the real cause, the fix that doubled the margin, and the three further layers a second node and a longer run exposed |
| I | [Classifier research history](#appendix-i-classifier-research-history) | The road to the current model, including two data-integrity bugs caught before they could inflate a number |
| J | [Test suite and verification record](#appendix-j-test-suite-and-verification-record) | What is covered by automated tests, and how each live claim was checked |
| K | [3D-printed parts and the fault-injection rig](#appendix-k-3d-printed-parts-and-the-fault-injection-rig) | The thirteen printable parts, the two enclosures, and the flywheel that makes an induced fault repeatable |
| L | [Reading the source](#appendix-l-reading-the-source) | Repository layout, the conventions the code holds to, and where to start reading |
| M | [Sustainability, scale and running cost](#appendix-m-sustainability-scale-and-running-cost) | What it saves, what it costs to run, and how it behaves at forty machines |
| N | [Glossary](#appendix-n-glossary) | Every term used in this report, in one place |

*Two conventions worth knowing before you start. Anything described as
**live-verified** was measured on the physical rig — not simulated, not
estimated; [Chapter 12](#chapter-12-proof-not-promises) collects every one of
those numbers and [Appendix J](#appendix-j-test-suite-and-verification-record)
records how each was checked. And anything **not** finished says so, in the same
sentence, in the same voice. A report that only says "it works" is worth exactly
as much as a machine that only says "I'm fine."*

---

# Part I — The system

# Chapter 1. The machine that never complains until it's too late

## 1.1 The problem, in one page

> **Month 0.** Ravi signs a lease on a shed off the highway. The CNC lathe
> arrives first and he stands at it all day, hand on the housing, because that
> is the only diagnostic tool he owns. The air compressor goes outside, under a
> tin sheet, where it cycles on its own pressure switch and nobody stands near
> it at all. The lathe is the machine he watches. The compressor is the one
> that will fail.

Machines don't send a text before they fail. They get a little louder, run a
little hotter, vibrate a little wrong — for days, sometimes weeks — and then one
Tuesday morning they don't start at all. By the time a person notices, it is
usually because something already broke. The repair is the small cost. The two
weeks of a dead machine and a slipped order book is the real one.

Large plants solve this with condition-monitoring systems that cost more than
Ravi's lathe. Small shops solve it by putting a hand on the housing, which works
right up until the day nobody happens to be standing there.

That day is most days, for most machines. A lathe has an operator at it, so a
lathe screams and somebody hears it. A compressor under a tin sheet, a borewell
pump on a night timer, a dust blower at the far end of the shed — those run for
hours with nobody within earshot, and they are the machines this report is
about. Every machine monitored from here on is one that runs unattended,
because a trip at 02:40 only means anything on a machine nobody is watching.

**EdgeAI Predictive Monitor** is a sensor pod that clips onto a machine, listens
to how it vibrates and sounds, and learns what normal is *for that specific
machine*. When it hears normal drifting away, it doesn't just put a sad icon on
a dashboard nobody is looking at. If it is confident enough, it reaches out and
**stops the motor** — before "a little wrong" becomes a seized bearing.

That last sentence is the point of this whole document. This system is allowed
to *act*, not only to observe. A dashboard that emails you is a respectable
product. A system that reaches out and stops the machine is a different category
of thing: sensing, deciding and *doing*, in one loop, with nobody required to be
watching at the moment it matters.

System at a glance: sensor pods and satellite nodes feed one base station, which fans out to the dashboard, a phone, the status lights, and — on a confirmed fault — a motor-stop command

> **[PHOTO: hero shot — the assembled base station clipped to the test rig, machine running, status ring lit]**

## 1.2 What it actually does

* **Watches.** An accelerometer and a microphone sample a machine's vibration
  and sound tens of thousands of times a second, right at the machine.
* **Reduces.** The sampling chip turns that firehose into a compact spectrum
  plus a handful of shape statistics, several times a second, so nothing large
  ever has to travel anywhere.
* **Learns.** During a short guided setup, it trains a private model of what
  *this* machine's healthy state looks like — including each of the different
  ways it normally runs. Training happens on the UNO Q itself. No two machines
  share a baseline, because no two machines vibrate the same.
* **Notices.** Every new frame is scored against that baseline in real time and
  lands on healthy, warning or fault.
* **Diagnoses.** A second, separate model — trained in Edge Impulse, running
  on-device — names *which kind* of fault it is hearing: a bearing going, an
  imbalance, a loose mount. That one is trained per **machine type**, so five
  identical pumps share one model instead of five training runs.
* **Knows when the machine is off.** A dedicated gate tells running from
  stopped, so a switched-off machine reads as *idle*, not as *broken*. This
  turned out to be the single hardest measurement in the project
  ([Chapter 8](#chapter-8-the-day-it-stopped-itself)).
* **Acts.** On a confirmed fault, it stops that machine's motor — and refuses to
  let it restart until a person clears it by hand.
* **Tells someone.** A light on the machine, a live dashboard, and a phone
  alert, so a human finds out without staring at a screen.
* **Scales.** The base station watches its own machine directly; **satellite
  nodes** watch other machines over Wi-Fi. Adding the tenth machine is a
  power-up-and-onboard job, not a cabling job.

## 1.3 Where the project actually stands

| Capability | Status |
|---|---|
| Vibration + audio sensing (base station) | Built · live-verified on hardware |
| Guided six-step setup, per-machine anomaly model | Built · live-verified on hardware |
| Multi-condition training (no load / full load) | Built · live-verified on hardware, with a measured sensitivity cost ([§5.6](#chapter-5-teaching-it-what-normal-feels-like)) |
| Running/stopped gate with measured noise floor | Built · live-verified on hardware |
| Trip-output mapping confirmed by really stopping the machine | Built · live-verified on hardware |
| Physical motor stop on confirmed fault, latched | Built · live-verified on hardware, both directions |
| Fault-type classifier (Edge Impulse, per machine type) | Built · runs on-device · trained on 541 real captures from this rig |
| Microphone channel in the two models | **Muted** — measured, live in the UI, zeroed in the model input ([§5.4](#chapter-5-teaching-it-what-normal-feels-like)) |
| Live dashboard (5 tabs, live charts, controls, global trip banner) | Built · live-verified on hardware |
| Status ring + on-board LED matrix | Built · live-verified on hardware |
| Wi-Fi onboarding via captive portal (base station) | Built · live-verified on real phones |
| Satellite sensor nodes over Wi-Fi/MQTT | Built · live-verified on a physical XIAO ESP32-S3, sensor by sensor |
| Phone alerts (Telegram) | Built · live-verified against a real bot and a real phone |
| Per-motor relay (cutting electrical power, not just motion) | **Not built** — [Chapter 13](#chapter-13-whats-next) |

## 1.4 Why this counts as Physical AI

Plenty of monitoring products stop at "notify a human." That is a real product,
but the intelligence never touches the physical world — it only narrates it.

The bar this project set itself is stricter: the loop from *sensor reading* to
*motor stopping* has to close with no human in it, end to end, on real hardware,
repeatably. [Chapter 8](#chapter-8-the-day-it-stopped-itself) is that loop,
including the mistakes made getting it trustworthy enough to arm.

Everything else in this report — the sensors, the wireless nodes, the models,
the dashboard — exists to keep that one loop honest and fast. Ravi's shop is the
excuse. The trip is the point.

## 1.5 The year this report follows

The chapters run in the order a real shop would meet them, and one shop's year
is used throughout to keep the "why" attached to the "what". Everything
technical in each chapter stands on its own; the shop is there so it is always
obvious what the engineering is *for*.

| | | Chapter |
|---|---|---|
| **Month 0** | The shed opens. Nobody is monitoring anything. | [1](#chapter-1-the-machine-that-never-complains-until-its-too-late) |
| **Month 1** | One sensor pod goes on the air compressor. | [3](#chapter-3-building-the-base-station) |
| **Month 1, day 2** | The compressor is commissioned: "just let it run for a bit." | [5](#chapter-5-teaching-it-what-normal-feels-like) |
| **Month 7** | A borewell pump and a dust blower, across the yard, out of cable reach. | [4](#chapter-4-growing-the-fleet) |
| **Month 9** | A second pump. One classifier now covers both. | [6](#chapter-6-naming-the-fault), [7](#chapter-7-training-the-classifier-with-edge-impulse) |
| **Month 11** | 02:40 on a Tuesday. Something stops itself. | [8](#chapter-8-the-day-it-stopped-itself) |
| **Month 12** | Ravi runs more machines than he can personally watch. | [13](#chapter-13-whats-next) |

---

# Chapter 2. Why the Arduino UNO Q

> **Month 1.** Ravi's shed has one spare socket, a lot of aluminium dust, and no
> room whatsoever for a rack. Anything that needs three boards, two power bricks
> and a fan is not going to survive its first week in there.

## 2.1 One board doing four jobs at once

This system has to do four things that normally do not live on the same board:

1. Sample two sensors at tens of thousands of samples per second and never miss
   a window — that is a job for a microcontroller with real-time guarantees.
2. Run FFTs and statistics on those windows continuously, without stealing time
   from step 1.
3. **Train** a neural network, from scratch, in the field, while a technician
   waits — that is a job for a Linux machine with a real Python stack.
4. Serve a live dashboard, run an MQTT broker, hold a database of assets, and
   talk to Telegram — that is a job for a networked server.

The conventional answer is two or three boards: a microcontroller for 1–2, a
single-board computer for 3–4, and a bridge between them that somebody has to
design, debug and power. The UNO Q is that whole arrangement already built,
already routed, already sharing one power supply and one USB connector.

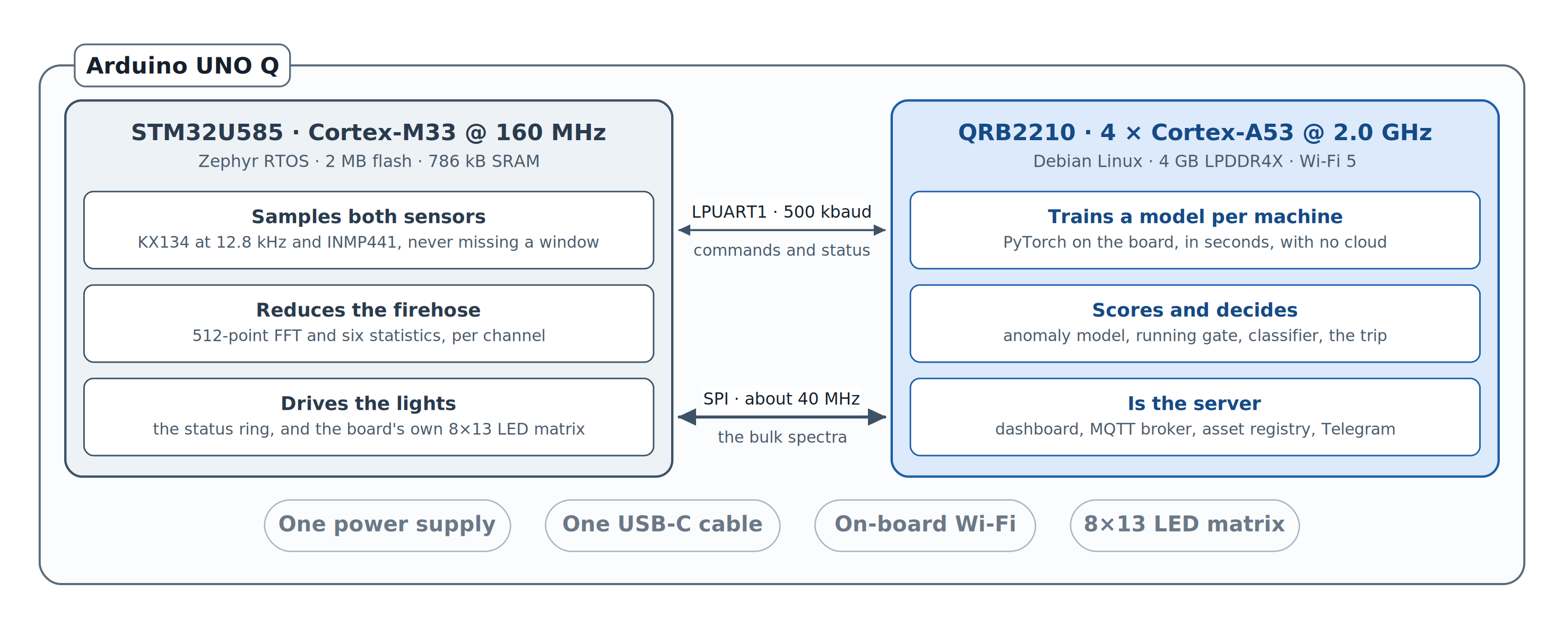
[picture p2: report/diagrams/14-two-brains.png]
One board, two processors: the STM32U585 samples and reduces, the QRB2210 Linux side trains and decides, and both links between them stay inside the board


**What we actually use, and where:**

| UNO Q capability | What it does in this project |
|---|---|
| **STM32U585 (Zephyr RTOS)** | Samples the KX134 over SPI and the INMP441 over SAI, runs the FFTs, computes six statistics per channel, drives the WS2812 ring and the LED matrix |
| **QRB2210 (Debian Linux, quad-core)** | Trains and runs the per-machine autoencoder in PyTorch, runs the Edge Impulse fault classifier, holds the asset registry, serves the dashboard, hosts the MQTT broker, publishes trips |
| **LPUART1 between the two** | Control-plane RPC between the halves, at 500 kbaud |
| **Dedicated MCU↔MPU SPI** | The bulk telemetry path — full-resolution spectra at ~40 MHz, so the control link never has to carry them |
| **On-board 8×13 LED matrix** | Fleet-wide health summary, readable across a workshop with no laptop open |
| **On-board Wi-Fi** | The shop network client, the MQTT broker's home, *and* a fallback access point for onboarding |
| **Arduino App Lab** | Packaging, deployment and secret management for the Linux-side application — see [§2.3](#chapter-2-why-the-arduino-uno-q) |
| **Adreno 702 GPU** | Evaluated for model inference. Confirmed working via Vulkan, and then deliberately **not** used — see [§2.4](#chapter-2-why-the-arduino-uno-q) |

## 2.2 The part that would be hardest to replace

Not the sensing. Not the dashboard. **The on-device training.**

Commissioning means a technician walks up to a machine, runs it for a few
minutes, and expects a trained, working monitor before they walk away. That is
only possible because the QRB2210 side is a genuine Linux computer running
genuine PyTorch — it fits and trains a small dense autoencoder locally, in
seconds, with no cloud round trip and no data ever leaving the building.

Take the Linux half away and the design changes shape completely: you are now
shipping every machine's vibration signature to a server, waiting on a training
job, and pushing a model back — which turns a five-minute walk-up task into a
workflow with a network dependency, a queue, and a data-governance conversation.
Take the microcontroller half away instead and you lose the deterministic
sampling that makes the spectra worth training on in the first place.

The UNO Q is one of the few boards where "sample it properly" and "train on it"
are the same purchase order.

## 2.3 What App Lab actually does here

App Lab is not a nicety in this build; it is the thing that makes the Linux half
shippable rather than a pile of scripts somebody has to remember to start.

* **One application, one deploy.** `base-station/app.yaml` declares the app's
  name, its icon and the ports it exposes — 8080 is the dashboard. App Lab
  builds it, ships it to the board and runs it in its own container. The build
  script in
  [Appendix C](#appendix-c-build-one-yourself) is a thin wrapper around that.
* **Secrets stay out of the repository.** The Telegram bot token is an App Lab
  **brick** variable (`arduino:telegram_bot`), typed into App Lab's own
  interface, never committed and never printed. With the token unset, every
  alert path in the code no-ops cleanly rather than crashing — which is the
  state the current build ships in, and which is why the Alerts tab says so out
  loud instead of pretending.
* **Both halves in one project.** The Zephyr sketch under
  `base-station/sketch/` and the Python application under
  `base-station/python/` are flashed and deployed from the same tool, which
  matters a great deal when a wire-format change has to land on both sides at
  once ([Appendix F](#appendix-f-wire-protocol-specification)).

The honest note: the frontend is deliberately **not** built with a Brick. The
dashboard is plain HTML, CSS and five self-contained JavaScript modules with no
framework, no bundler and no build step — because a live 15 frames-per-second
Plotly view with per-asset state was easier to keep correct as explicit code
than as a generated UI. Bricks earn their keep on the parts where the
integration is the hard bit, which for this project is the bot token, not the
charts.

## 2.4 What we pushed on, and what pushed back

An honest hardware section says where the board's limits are, not just its
features. Three things were tested to the edge:

* **Accelerometer output data rate.** The KX134 will run at 25.6 kHz. We run it
  at **12.8 kHz**. At the full rate, the sampling thread stopped yielding often
  enough and starved the inter-processor link outright — telemetry frames went
  to zero. 12.8 kHz is eight times the original baseline with real headroom
  left. Full numbers and the reasoning:
  [Appendix G](#appendix-g-sensor-configuration-envelope).
* **The internal UART.** Raised from the stock 115200 to **500000 baud** after
  root-causing why higher rates failed: the Linux side derives its baud from a
  32 MHz reference with 16× oversampling, so 1 Mbaud and 2 Mbaud land on
  divisors of 2 and 1 — right at the edge where the receiver loses sampling
  margin. They boot beautifully and then wedge twenty minutes later, which is
  the worst kind of working. 500000 lands on a divisor of exactly 4 and survived
  every soak test, including one longer than the exposure that broke the next
  rate up.
* **The GPU.** The Adreno 702 was spiked properly rather than assumed. Two
  findings: the vendor TFLite GPU wheels are compiled for ARMv8.1 atomics this
  CPU does not have, so loading them kills the process outright — not an
  exception you can catch, an illegal instruction that takes the whole
  application with it. And via a Vulkan backend that *does* work, bit-exact
  against CPU, the measured speed-up stayed at ~1.0× from a single vector all
  the way up to a 256-node batch. These models are 536 numbers wide. Sending
  them to a GPU is chartering a cargo ship to post a letter.
  **Staying on CPU is a finding, not a shortcut.**

None of these are complaints. They are the kind of thing you only learn by
running a board hard for weeks, and all three are documented here so the next
person doesn't have to rediscover them.

---

# Chapter 3. Building the base station

> **Month 1.** One pod, one machine, one afternoon. Ravi does not want a pilot
> programme. He wants to know whether the compressor out under the tin sheet is
> going to be fine, because that is the one nobody is standing next to.

## 3.1 One board, one machine

The simplest useful version of this system is one sensor pod bolted to one
machine. That is the **base station**: an Arduino UNO Q with an accelerometer
and a microphone wired to it, watching one motor, showing its own status on a
light, and serving the dashboard.

If you stopped right here you would already have something most small shops
don't: a machine that tells you it is getting sick before it collapses.
Everything else in this report is this same idea, repeated and connected.

> **[PHOTO: base station fully wired and clipped to the test rig — sensor, board and status ring in one wide shot]**

## 3.2 What you are building

Three peripherals hang off the real-time half of the board, and nothing hangs
off the Linux half:

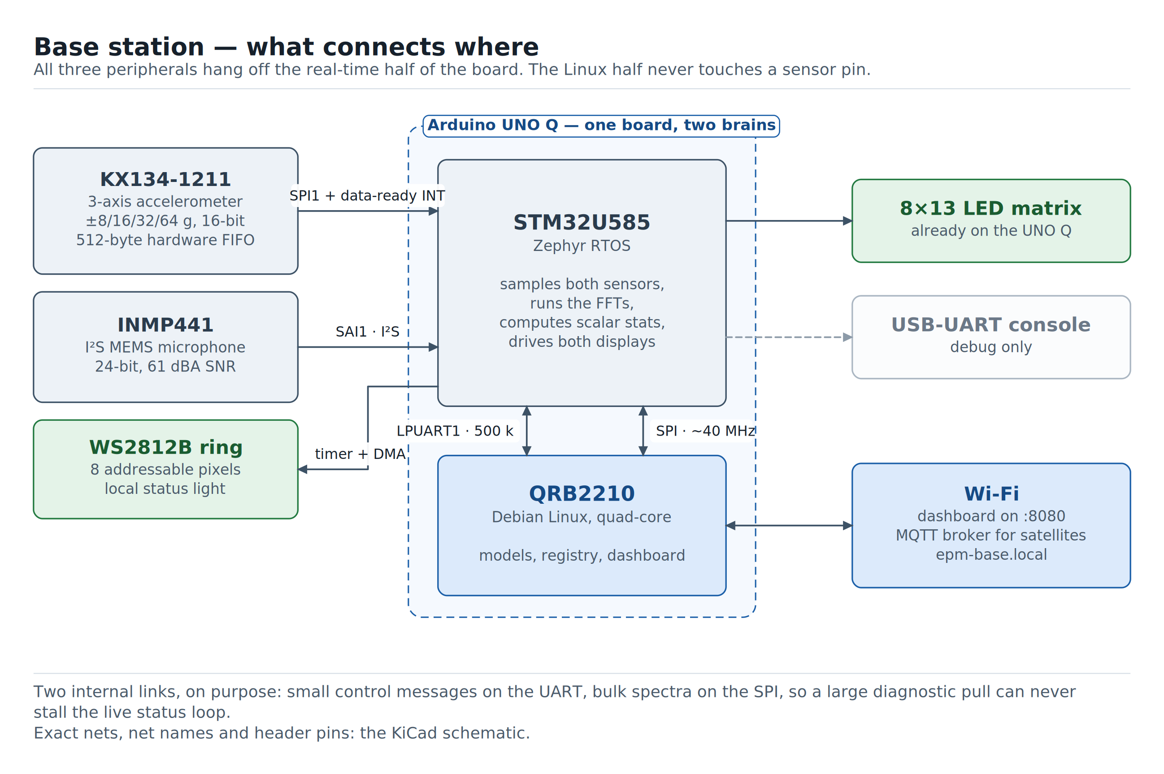
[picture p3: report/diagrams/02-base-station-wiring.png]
Base station block wiring: the KX134, INMP441 and WS2812 ring all connect to the STM32U585 side; the QRB2210 side handles Wi-Fi and the dashboard


* The **KX134-1211** accelerometer on SPI, with a chip-select and a
  buffer-full interrupt line. Its 512-byte hardware FIFO is doing real work
  here: without it the host would need servicing roughly every 39 microseconds
  at full rate, which is a hostile interrupt load for a chip that also has FFTs
  to run.
* The **INMP441** microphone on the STM32's SAI peripheral, giving 24-bit
  digital audio with no analogue front end to design.
* The **WS2812B ring** on a timer channel with DMA, so the strict bit-banged
  timing those LEDs need never depends on the scheduler being free.

The exact pin for every net is in
[Appendix B](#appendix-b-wiring-and-pinout-reference), which also carries the
real KiCad schematic. The parts, prices and buy links are in
[Appendix A](#appendix-a-bill-of-materials). Both appear exactly once in this
document, on purpose — there is one place to look for each.

**Where you put the sensor matters as much as which sensor you bought.** An
accelerometer read through a soft or loose mount is a low-pass filter you did
not ask for, and it removes exactly the high-frequency content that early
bearing faults live in. Rigid coupling to the machine housing, as close to the
bearing as the geometry allows, is not an accessory decision.

## 3.3 First light

The full command-by-command build is [Appendix C](#appendix-c-build-one-yourself).
The short version is two steps: flash the sketch onto the STM32 side through
Arduino App Lab, then run one script that builds, pushes and starts the Linux
application and prints the board's own LAN URL.

Open that URL and the machine appears on its own. Nothing has been trained yet
— that is [Chapter 5](#chapter-5-teaching-it-what-normal-feels-like) — but the
sensing half of the loop is already complete and watchable: live vibration and
audio spectra, live time-domain traces, and a status ring that has gone solid
the moment real data started flowing.

## 3.4 Why there are two chips talking to each other

The STM32U585 side is close enough to the hardware to keep up with a sensor that
does not wait for anyone. The QRB2210 side has the memory and the operating
system to train a model and serve a web page at the same time. Between them run
two separate links, and the split between those two links is deliberate:

* **LPUART1** carries small control messages — remote-procedure calls, status
  pushes, statistics queries. A few numbers, often.
* **A dedicated SPI bus** carries the bulk telemetry — full-resolution spectra
  and raw diagnostic pulls. A lot of numbers, occasionally.

Keeping them apart means a large diagnostic capture can never stall the
real-time status loop that everything else depends on. That separation was not
free — it was the result of an earlier design where everything shared one link
and a bulk stream wedged the control channel. [Chapter 10](#chapter-10-under-the-hood)
has the full data path; [Appendix F](#appendix-f-wire-protocol-specification)
has the framing.

---

# Chapter 4. Growing the fleet

> **Month 7.** The yard now holds a borewell pump on a night timer, a coolant
> pump, and a dust blower at the far end of the shed. None of them is within
> cable reach of the compressor, and Ravi is not running conduit across a yard
> for a monitoring system. None of them has anybody standing near it either,
> which is exactly why they are on the list.

## 4.1 Machine number two

Running wire to every new machine isn't a plan, it's a standing chore.

**Satellite nodes** solve that. Each one is a small self-powered sensor pod —
same accelerometer, same microphone, same status ring as the base station — that
watches its own machine and reports over Wi-Fi. The dashboard does not
distinguish wired machines from wireless ones. A satellite just shows up as one
more asset in the list, next to the original.

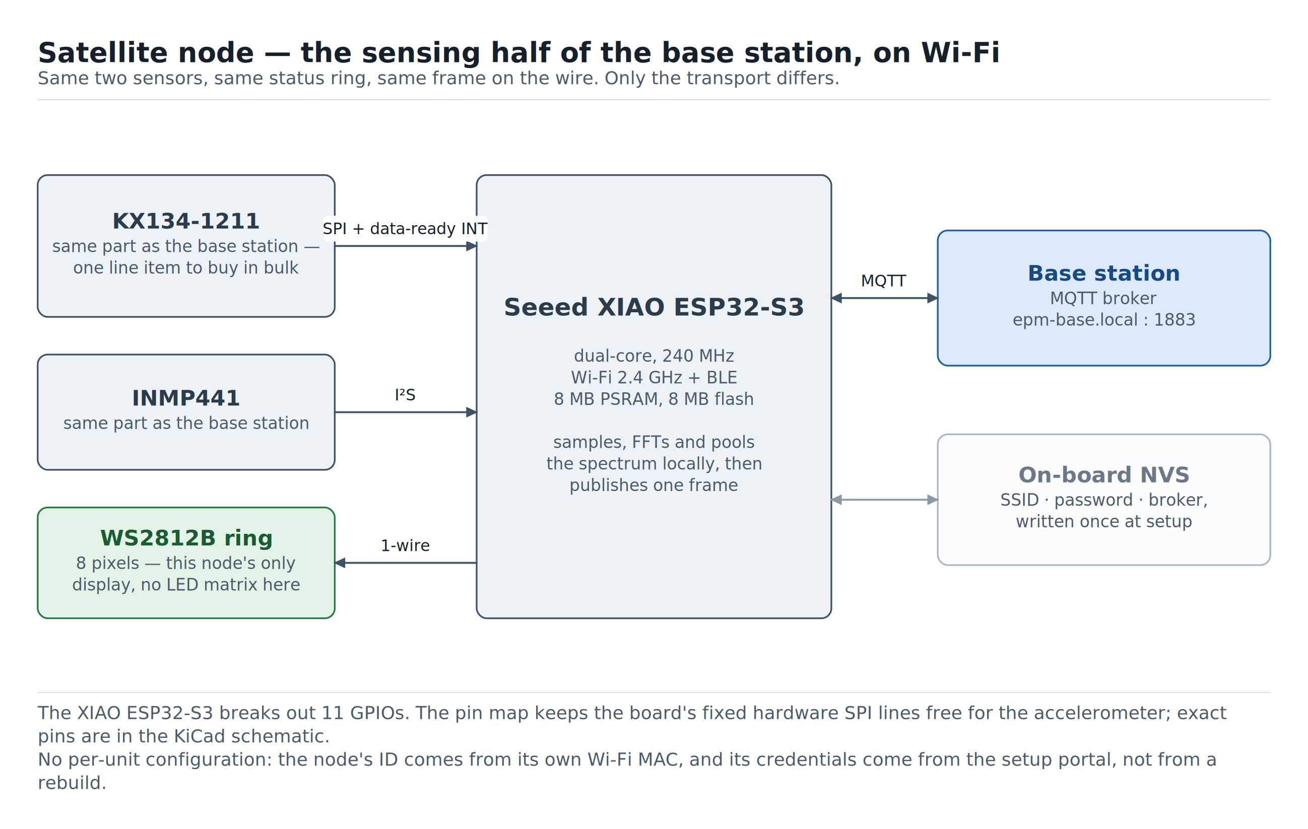
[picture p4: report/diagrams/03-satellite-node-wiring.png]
Satellite node block wiring: the same KX134 and INMP441 on a XIAO ESP32-S3, publishing over Wi-Fi to the base station's MQTT broker


> **[PHOTO: a satellite node mounted on a second machine, powered and running]**

## 4.2 Onboarding one, start to finish

This is the part most projects gloss over, so here it is in full — because it is
the difference between a demo and something a shop can actually adopt.

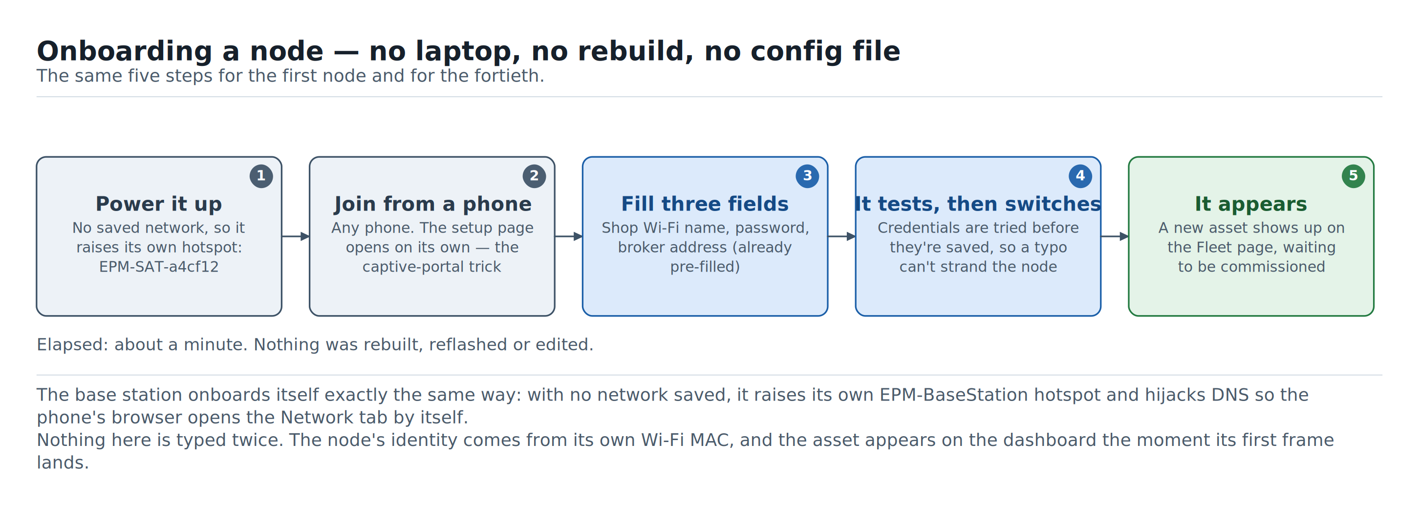
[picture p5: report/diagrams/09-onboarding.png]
Onboarding a node: power up, join its hotspot from a phone, fill three fields, it tests and switches over, and the asset appears on the dashboard


**1. Power it up.** A node with no saved credentials does not sit there blinking
an error. Its ring goes steady magenta — *waiting for setup* — and it raises
**its own Wi-Fi access point**, named from its own hardware address —
`EPM-SAT-a4cf12`. The name is unique per node, so ten unconfigured
nodes on a bench are ten distinguishable networks, not one collision.

**2. Join it from any phone.** No app. The moment the phone joins, the setup
page opens by itself. That is the captive-portal mechanism real airport Wi-Fi
uses — the node answers every DNS query with its own address, so whichever
connectivity-check URL the phone reaches for lands on the setup form instead,
and the operating system pops its browser open on it. The same trick, used for
good instead of for selling you thirty minutes of internet.

**3. Fill in three fields.** The shop's Wi-Fi name, its password, and the
address of the MQTT broker — which comes **pre-filled** with `epm-base.local`,
the base station's own mDNS name. It is a field rather than a constant because
mDNS is sometimes blocked on factory VLANs, and when it is, a technician needs
to be able to type an address rather than reflash a board.

**4. It tests before it commits.** Submitting does not blindly save. The node
tries the credentials first and only writes them to its non-volatile storage on
success, so a typo cannot strand a device on a machine you now need a ladder to
reach. On success its own access point drops and it joins the real network.

**5. It appears.** No pairing step, no ID to type in, no dashboard form. The
node derives its identity from its own Wi-Fi MAC and starts publishing; the
asset shows up on the Fleet page the moment the first frame lands, ready to be
named and set up.

> **[SCREENSHOT: the satellite setup portal on a phone, and the Fleet page with the new asset appearing]**

**The base station onboards itself the same way.** With no network saved, it
raises an `EPM-BaseStation` hotspot and runs the same DNS trick, redirecting any
request to its dashboard's Network tab — where the same "pick a network, type a
password" flow is waiting. That flow has been tested on real phones, and three
rounds of live testing went into details that only show up on real hardware:

* The network list is a set of **tappable buttons**, not a native autocomplete
  field. An earlier version used an HTML `<datalist>`, which mobile browsers
  render unreliably or, in several cases, not at all — the list simply never
  appeared, and the operator was left typing an SSID from memory.
* The warning that *"this page may close when you tap Connect — that's normal"*
  appears **before** the button rather than after it, because the device's own
  network switches out from under the page too quickly to read a message that
  only appears afterwards.

Both of those are one-line changes that no amount of desk testing would have
produced.

## 4.3 One format, every node

A satellite node and the base station's own sensing half speak the identical
language on the wire: the same generic *here is a channel, here is its spectrum,
here are its statistics* frame, whether it arrives over the internal SPI bus or
over MQTT from across the floor.

That is deliberate, and it buys three things:

* The scoring pipeline never learns which kind of node a machine is behind. It
  routes, validates and scores one frame shape.
* Adding a satellite is a wiring-and-power task, not a software task.
* It is what makes "one trained classifier covers every pump of this type"
  possible at all — a base-station-monitored pump and a satellite-monitored
  pump hand the model data shaped exactly the same way.

The frame layout, both framings and the schema that keeps the three codebases
from drifting apart are in
[Appendix F](#appendix-f-wire-protocol-specification).

---
# Part II — The intelligence

# Chapter 5. Teaching it what normal feels like

> **Month 1, day 2.** The pod is on the compressor and the dashboard is up. Ravi
> asks the obvious question — *so what does it think?* — and the honest answer
> is: nothing yet. It has never met this machine. Give it four minutes.

## 5.1 "Just let it run for a bit"

Before this system can say something is wrong, it has to know what *right*
sounds like — and every machine's right is different. A new compressor hums
differently from one that has run for a decade; a compressor's normal vibration
looks nothing like a borewell pump's.

So the first thing that happens with a new machine isn't detection, it's
listening. An operator opens the machine's setup drawer and works down a short
list of steps: name it, measure it switched off, run it, train it, and prove
which motor it is wired to. Four to six minutes later that machine has its own
model, its own thresholds, and a tested emergency stop.

> **[SCREENSHOT: the setup drawer open on step 3, showing two named conditions collecting — "Running 41/50" and "Full load 12/50"]**

## 5.2 The six steps

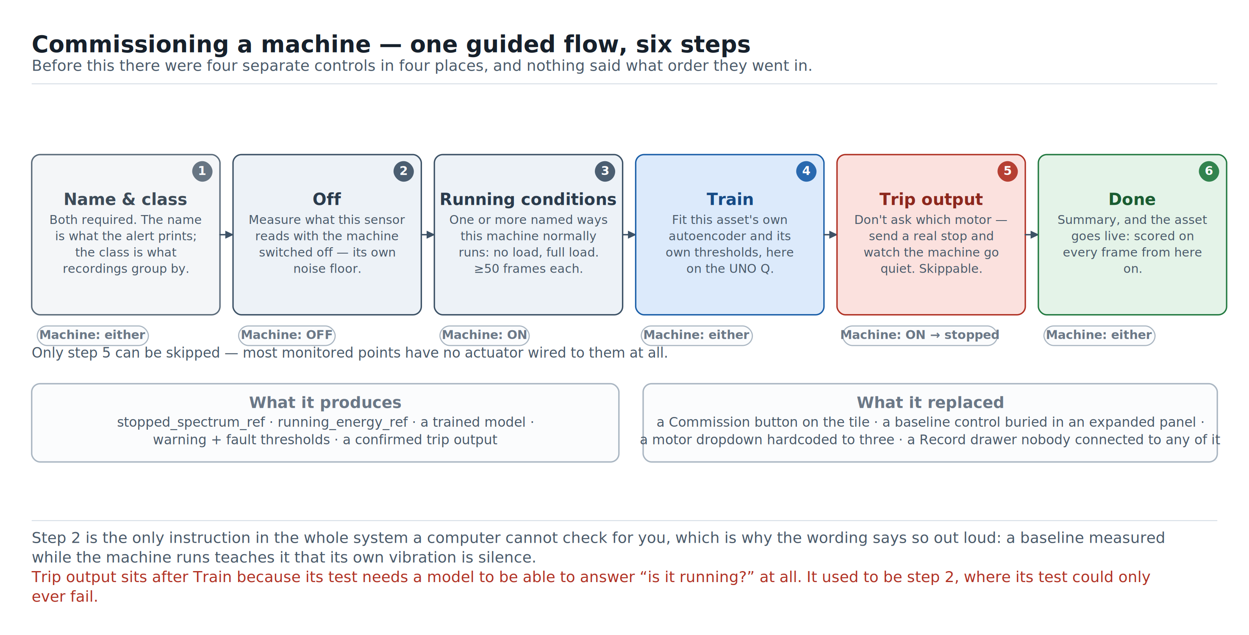
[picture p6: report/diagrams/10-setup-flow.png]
The guided setup: name and class, measure with the machine off, collect one or more running conditions, train, confirm the trip output by really stopping the machine, done


| # | Step | Machine | Required | What it produces |
|---|---|---|---|---|
| 1 | **Name & class** | either | yes | The name alerts print, and the class recordings group by |
| 2 | **Off** | **switched off** | yes | This sensor's own noise floor, per frequency bin |
| 3 | **Running conditions** | **running** | yes (≥1) | The training batch, the gate's running reference, and labelled healthy recordings |
| 4 | **Train** | either | yes | This asset's own model, its normalisation statistics and its two thresholds |
| 5 | **Trip output** | running → stopped by us | no | Which motor stops this machine — *confirmed*, not guessed |
| 6 | **Done** | either | — | A summary; the asset goes live |

**This replaced four separate controls in four different places.** Before it,
an operator had to find a Commission button on the machine's row, a stopped-
baseline control buried inside an expanded panel, a trip-motor dropdown
somewhere else again, and a Record drawer that nothing connected to any of them.
Nothing told them these were related, and nothing said what order they went in —
even though the order genuinely matters: without a stopped baseline the gate can
barely tell running from stopped, so a training batch collected before one was
calibrated against a weak gate.

Three details in that list are worth their own paragraph.

**Step 1 is mandatory, and that is new.** Neither a name nor an asset class used
to be required. Both are now, with no skip. The name is what a Telegram alert
and the trip banner print, and *"Tripped — esp32-a4cf12 at 02:40"* is the wrong
thing to read at 02:40. The class is what recordings are grouped by, and making
it optional would mean a silent conditional branch through the rest of setup:
recordings quietly not saved, discovered weeks later by somebody trying to train
a classifier. One typed word is cheaper than that branch. It also gets easier as
the fleet grows — on day one it is free text, and after that it is a pick-list
of classes that already exist.

**Step 2 is the one instruction no computer can check.** Nothing in the software
can confirm that the machine is actually switched off, so the wording says so
out loud rather than pretending: *"Switch the machine off. Confirm it has
stopped moving, then Start. Nothing here can check that for you — a measurement
taken while the machine runs teaches the system that its own vibration is
silence."* Why that measurement matters at all is
[Chapter 8](#chapter-8-the-day-it-stopped-itself).

**Step 5 used to be step 2, and moving it was a real correction.** The original
argument was appealing: the trip test *ends* with the machine stopped, which is
exactly the state step 2 needs, so the operator would switch the machine off
once instead of twice. That saving never existed. The test refuses to run unless
the gate reports the machine running; the gate cannot answer that at all until a
model exists; the model is not fitted until Train. At position 2 the test could
only ever fail — nothing was published, the machine never stopped, and the
operator switched it off by hand for step 2 anyway. The early position bought an
operator action it did not save, at the price of an untestable step on every
fresh asset. It is now step 5, where every precondition it needs already holds.

Setup state lives in memory only. Restart the dashboard mid-setup and the
current step restarts — half-collected batches are deliberately not persisted,
because a batch resumed across a restart is worse data than a fresh one.

## 5.3 Don't ask which motor. Prove it.

Step 5 is the one an operator remembers, and it is the design decision this
project is proudest of.

The old version was a dropdown with three motors in it, because the number three
was hardcoded in the frontend to match the bench rig. A factory with one motor
saw three options, two of which were fiction. Worse, whichever one the operator
picked was never verified — you found out whether "Motor 2" really stopped *this*
machine during the first real fault, which is the worst possible moment to
discover it was wired to the neighbouring one.

What happens now:

1. The motor rig **announces its own outputs** on connect, as a retained MQTT
   message. The dashboard shows exactly the outputs that exist. One motor on day
   one, five when there are five, with no dashboard change.
2. The operator leaves the machine running and presses **Test** next to a
   candidate output.
3. The system sends a **real stop** — the same command, same code path, same
   payload as a genuine trip — and then watches this node's own vibration gate.
4. The machine goes quiet within the confirm window → the mapping is
   **confirmed**, and stamped with the date. It keeps running → wrong output, or
   a broken trip path; try the next candidate.

That buys three things beyond deleting a dropdown. The mapping is verified
against physics rather than against somebody's memory. It is a genuine
end-to-end test of the entire trip path — MQTT topic, rig subscription, motor
halt, gate confirmation — performed at setup time instead of during the first
emergency. And it is honest about what it doesn't know: a manual *"use without
testing"* fallback exists for a machine that can't be cycled right now, and it
records the mapping as **unconfirmed**, and says so on the tile. Unconfirmed is
honest. A confirmed-looking guess is not.

The safety invariant survives all of this intact: **the only command this system
can ever send is stop.** There is no code path anywhere that can set a speed or
start a machine. The operator starts the machine by hand, at the machine, both
before the test and after it.

## 5.4 What "normal" means to a machine

Every incoming frame becomes a **feature vector** — a compact numerical
fingerprint of that moment, not the raw waveform.

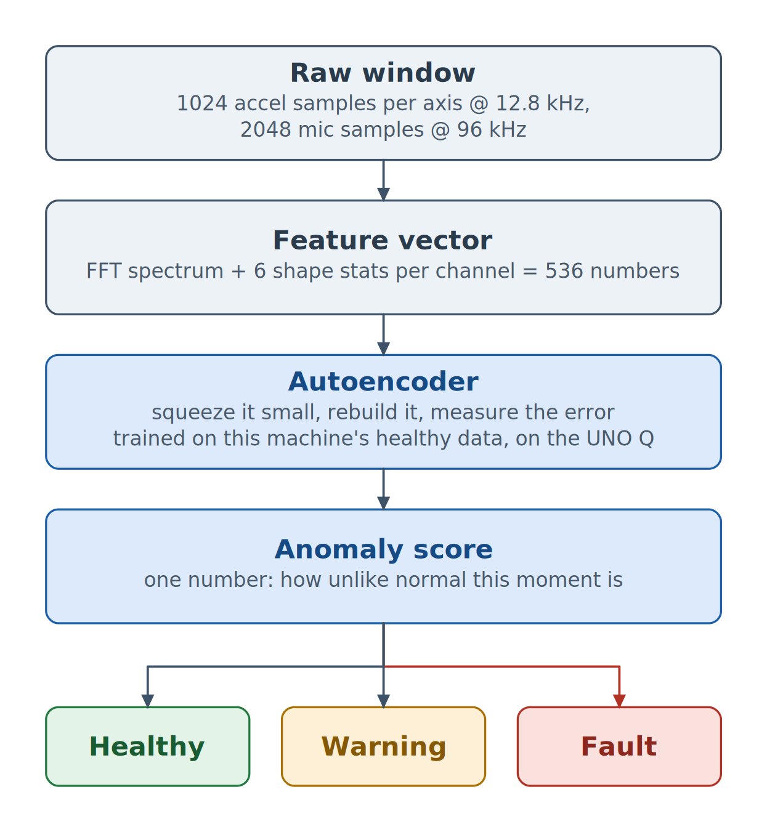
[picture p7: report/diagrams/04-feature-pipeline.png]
Feature pipeline: raw window to feature vector to autoencoder to anomaly score to status


*One frame's journey, run against each machine's own model.*

For each sensing channel — vibration on X, Y and Z, plus audio — the system
keeps two very different kinds of information:

* **The spectrum.** How much energy sits at each frequency, peak-normalised so
  the model learns the *shape* of the spectrum rather than how hard the machine
  happens to be loaded at that instant.
* **Six shape statistics.** RMS, peak, crest factor, kurtosis, skewness and
  standard deviation, computed on the time-domain window. These describe things
  a spectrum alone hides — particularly impulsiveness, which is exactly what a
  failing bearing produces.

Those statistics are computed **per axis**, never on a combined tri-axial
magnitude. That is not a stylistic choice: combining X, Y and Z into one
magnitude erases the directional signature an imbalance produces, and an offline
sweep over real captures measured the difference as **+1.8σ fused versus +38.5σ
per-axis** on the same data. It is one of the highest-leverage decisions in the
whole pipeline, and it came out of measurement rather than intuition.

The result is a 536-number vector: 128 spectral bins × 4 channels, plus 6
statistics × 4 channels.

**The microphone's 134 of those numbers are currently zeroed, deliberately.**
The rig's machines sit close enough together that one motor's noise reaches
another node's microphone, and that crosstalk pushed a node into Fault while its
own accelerometer read perfectly healthy. Vibration does not travel across a
bench that way; sound does. So `features.MUTED_CHANNELS` makes the microphone
contribute a constant 0.0 to every vector the one shared builder produces —
which is the input to the autoencoder, to the Edge Impulse classifier and to
every saved capture alike.

Three things about that choice are worth stating, because it is the single
largest caveat on every result in this report:

* **Muted, not removed.** The columns still exist, so the vector is still 536
  numbers wide, the Edge Impulse project keeps its axes, and the capture schema
  is byte-identical. Dropping the microphone from the sensor configuration
  instead would have changed the input dimension to 402 and invalidated every
  recording already taken.
* **Only the model input is muted.** The microphone is still sampled, still
  plotted live on the dashboard's spectrum view, and still recorded in captures.
  Nothing about the sensing path changed.
* **Every capture records what was muted when it was taken**, because a muted
  channel's zeros are indistinguishable from a genuinely silent one after the
  fact — so a dataset recorded muted can never be silently pooled with one
  recorded unmuted.

The running/stopped gate ([§5.8](#chapter-5-teaching-it-what-normal-feels-like))
had already excluded the microphone for the same reason; this closed the
remaining path. It also means **every measured result in
[Chapter 12](#chapter-12-proof-not-promises) is vibration alone.** Re-enabling
it is a mounting problem rather than a software one — it is one constant — and
it is item 1 in [Chapter 13](#chapter-13-whats-next).

## 5.5 The autoencoder, and why an unsupervised model

An **autoencoder** is a small neural network whose only job is to squeeze its
input down through a bottleneck and rebuild it. Train one on nothing but a
machine's healthy data and it becomes very good at rebuilding that machine's
normal — and noticeably worse at rebuilding anything else. The size of that gap
is the **anomaly score**.

The reason for choosing this shape over a supervised classifier as the primary
detector is practical, not academic: **nobody has labelled fault data for a
machine that has not failed yet.** A supervised model needs examples of the
thing you are trying to prevent. An autoencoder needs only examples of the
machine behaving, which is the one thing every shop has an endless supply of.
That is what makes setup a five-minute job instead of a data-collection
campaign.

The network is deliberately small — a symmetric dense encoder/decoder whose
hidden and bottleneck widths scale from the input dimension rather than being
hardcoded, so the same code fits a mic-only node and a full four-channel one.
That scaling is why muting a channel rather than removing it costs nothing: the
network's shape is set by the input dimension, and the input dimension does not
move.
Training a fresh model takes seconds on the QRB2210, with live percentage
progress pushed to the browser, and the operator is explicitly told they can
walk away: *"You can leave this page — it finishes on its own."*

## 5.6 More than one kind of normal

A machine does not have one healthy state. A compressor idling, a compressor
pumping up to pressure and a compressor holding it vibrate differently, and all
three are fine.
Show the model only one of them and the other two are off-manifold — which means
the machine reads as faulty every time the shift changes what it is doing.

Step 3 therefore collects **named conditions**, not one batch. The default and
only mandatory one is *Running*. An operator can add *No load*, *Full load*, or
anything they want to type, and each collects its own ≥50 frames with its own
live counter. Day one, on a simple machine, they add none and the step behaves
exactly as a single commissioning batch used to.

Those frames go three places at once:

1. **Pooled into one training batch.** All conditions together, one model, one
   healthy manifold that now spans the machine's real duty range.
2. **The gate's running reference** is taken from the **quietest** condition,
   not the pooled median. The gate's running threshold is a fraction of that
   reference, and it still has to call the machine's quietest legitimate running
   state "running". A pooled median dragged upward by a loud full-load condition
   would push that line above the machine's own no-load level, and a machine
   idling normally would read as stopped.
3. **Saved as recordings**, one file per condition, all under the same label
   `healthy`, with the condition name recorded alongside. The shared label is
   deliberate: `healthy_no_load` and `healthy_full_load` as separate labels would
   hand the fault classifier ([Chapter 7](#chapter-7-training-the-classifier-with-edge-impulse))
   two classes that both mean "fine".

### The cost of this, measured

Pooling conditions widens the healthy reconstruction-error spread, so the
thresholds — which are placed relative to that spread — sit higher, and
sensitivity drops. That was expected. What was *not* expected is how much.

Measured on the rig, same frame counts, same everything else:

| Training conditions | Warning threshold | Fault threshold |
|---|---:|---:|
| `slow_90rpm` alone | 0.146 | 0.292 |
| `slow_90rpm` + `fast_150rpm` | 0.745 | 1.490 |

**5.1× wider.** And it has a consequence you can watch happen: a 220 RPM
overspeed — 2.4× the commissioned speed, an unambiguous fault — scored 1.851 and
tripped in about eleven seconds under one condition. Under two conditions it
never crossed 1.490 at all.

That is a real sensitivity loss, and it is stated here rather than buried,
because the feature is genuinely useful and genuinely not free. The trade is
still the right one for a machine with a real duty cycle: a slightly higher line
that never false-alarms on a normal load change beats a tight line that cries
wolf at the start of every shift. But it should be quantified per machine before
being promised to an operator, and the honest next step — per-condition
thresholds, or a condition-aware model — is on the roadmap in
[Chapter 13](#chapter-13-whats-next) rather than claimed as done.

## 5.7 From a score to a status

A single number is not a status. Two thresholds turn it into one, and both are
derived from what this machine's own healthy data actually looked like:

* **Warning** at μ + 8σ of the healthy score distribution.
* **Fault** at μ + 15σ, with guards so that fault > warning > 0 always holds
  even for a degenerate near-zero-spread batch.

The margins are wide because healthy scores cluster very tightly right after
training on that same data, so a few sigma is a tiny absolute distance.

A fixed global threshold cannot work here, and this is worth being explicit
about because it is the most common way a project like this fails quietly: the
autoencoder's reconstruction error is measured in units set by that machine's
own spectrum. What reads as comfortably healthy on one motor reads as a fault on
another. Calibrating per machine is what makes a real fault actually cross the
line on the dashboard instead of sitting in the noise.

Crossing the fault line once is not enough either — a fault must persist across
consecutive frames before the status changes, so one noisy sample never cries
wolf.

## 5.8 Knowing when the machine is simply switched off

There is a third thing scoring a frame, alongside the model: a **running/stopped
gate**. Its whole job is to answer "is this machine even turning right now?"
from vibration energy alone.

It matters for three reasons. A machine switched off an hour ago should read as
*idle*, not keep displaying whatever status it held while it was last running.
The trip-output confirmation in [§5.3](#chapter-5-teaching-it-what-normal-feels-like)
is nothing but this gate, watched carefully. And when a real trip fires, the only
honest way to know it actually worked is to watch the machine go quiet.

Getting that measurement right turned out to be the hardest single problem in
the project — the sensor's own noise floor is loud enough to look like a running
motor. That story is [Chapter 8](#chapter-8-the-day-it-stopped-itself), and the
full investigation is [Appendix H](#appendix-h-motor-state-gate-calibration).

## 5.9 How hard can you push the sensing?

A reasonable question from anyone planning to point this at a machine with a
different fault signature: what is the ceiling?

Short version — the accelerometer can run to **25.6 kHz**, giving usable
frequency content to about 12.8 kHz, and the FFT depth and how much of it goes
on the wire are both independent, tunable knobs. What we run today is one point
in that envelope, chosen for stability, not the maximum.

The full envelope — every rate, every bin count, what each costs in bandwidth
and in CPU, what happens at the extremes, and how to change it — is
[Appendix G](#appendix-g-sensor-configuration-envelope).

## 5.10 Why train here rather than in the cloud

Two reasons, in this order.

**Setup has to feel instant.** A technician standing at a machine will wait a
minute. They will not wait for a queued cloud job, and they certainly will not
come back tomorrow. Training locally keeps commissioning something you start and
finish in one visit.

**The data never has to leave.** A machine's vibration signature is a fairly
intimate record of how a business operates — how many hours it runs, how hard,
and when it stopped. Keeping training on-device means "does our data leave the
building?" has a clean answer — *only if you choose to send it* — which stops
being a technical question and starts being a procurement one the moment a
customer is larger than one shop.

---

# Chapter 6. Naming the fault

> **Month 9.** A second borewell pump goes in, same model as the first. Ravi's
> reasonable expectation is that the system already knows something about
> pumps. He is right, and that is the whole point of this chapter.

## 6.1 Beyond "something's wrong"

Healthy / warning / fault answers *whether* something is off. It does not
answer *what*, and "what" is the difference between "stop everything" and
"order a bearing for Thursday."

So there is a second model: a supervised classifier that names the fault
category it is hearing — bearing wear, imbalance, a loose mount. It runs
on-device, on the same feature vector the anomaly model sees, and its result
appears next to the machine's status the moment there is a fault to explain.

> **[SCREENSHOT: an expanded asset row showing the fault-classification confidence bars]**

## 6.2 One model per machine *type*, not per machine

This is the important structural difference from
[Chapter 5](#chapter-5-teaching-it-what-normal-feels-like), and it is the reason
the two models are built completely differently.

The anomaly model is **per machine**, because it models *this unit's normal* and
normal is a property of one physical installation. The classifier is **per
machine type**, because what distinguishes a bearing fault from an imbalance is
a property of the *fault*, not of the unit — and pooling every pump's data
gives it far more to learn from than any one pump could.

Concretely: every asset carries an **asset class** (`pump`, `conveyor motor`,
…, the dashboard's own field placeholders), set in step 1 of setup. Recordings are grouped by that class, one
Edge Impulse project is linked per class, and the trained model that comes back
applies to every asset in it. Train once, cover the whole line.

The dashboard is built around that idea rather than bolting it on: the
Classifier tab shows **one card per asset class**, not one per node. The
normalisation baseline is fitted from every recording pooled across the class,
so units with slightly different mounting don't each drag the model in their own
direction.

## 6.3 What the classifier is, and is not, allowed to do

The classifier **names** faults. It never decides whether to stop a motor.

That separation is structural, not a policy someone has to remember: the trip in
[Chapter 8](#chapter-8-the-day-it-stopped-itself) runs off the anomaly gate
alone and has no code path that reads a classification. If the classifier is
ever wrong about *which* fault it is, the machine still stops — the label on the
alert is just wrong, which is a bad afternoon rather than a bad outcome.

An asset with no class assigned, or a class with no trained model, simply shows
the anomaly score and no classification. Nothing breaks, and nothing displays an
empty placeholder promising a feature that isn't configured.

How that model actually gets built, uploaded, trained and fetched is the whole
of the next chapter.

---

# Chapter 7. Training the classifier with Edge Impulse

## 7.1 Why Edge Impulse at all

Building a training pipeline from scratch for the fault classifier was genuinely
on the table, and it was the wrong use of the time available. Edge Impulse is
built for exactly this category of problem — labelled sensor data in, a
deployable embedded model out — and using it meant the effort could go into the
parts nothing provides off the shelf: the running/stopped gate, the trip chain,
the fleet dashboard.

There is a second, structural reason. Keeping the classifier's training
completely outside this codebase is what keeps it structurally independent of
the safety path. The trip cannot depend on a model it has no code path to read.

## 7.2 The round trip

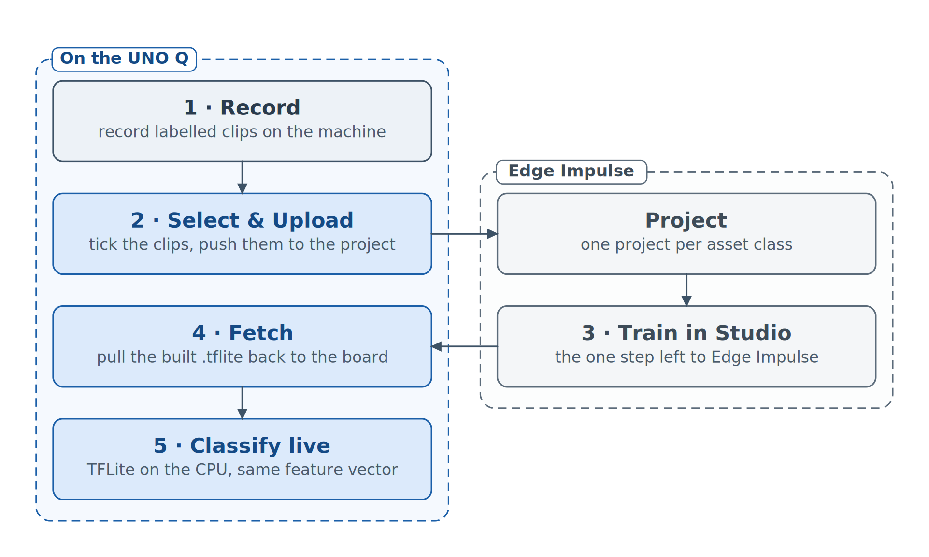
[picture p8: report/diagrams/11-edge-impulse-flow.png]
The Edge Impulse round trip: record on the machine, upload from the dashboard, train in Studio, fetch the built model back onto the board


*One project per asset class, not one per machine.*

Five steps, and only one of them happens outside the dashboard.

## 7.3 Record — capturing a fault without leaving the page

An operator hears something, or the anomaly score climbs, and wants that moment
kept. On the machine's row there is a **Record** drawer: type a label
(`healthy`, `bearing`, `unbalanced`, `loose` — previously used labels are
offered as suggestions so a fleet doesn't accumulate `bearing`, `Bearing` and
`bearing2`), optionally set a frame count, press Start.

Capture runs **server-side**. Closing the drawer doesn't stop it. Closing the
browser doesn't stop it. The row's record button just keeps pulsing until you
come back — which matters because the useful captures are the long ones, and
nobody wants to babysit a tab for four minutes next to a running machine.

Setup contributes to this automatically: every running condition collected in
step 3 is also saved as a `healthy` recording
([§5.6](#chapter-5-teaching-it-what-normal-feels-like)), so the *healthy* class
fills itself as the fleet is commissioned. The fault classes are the ones a
human has to go and produce.
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

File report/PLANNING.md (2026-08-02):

# Report planning — EdgeAI Predictive Monitor

Internal working doc. **Not** part of the submitted PDF. `REPORT.md` must stand
completely on its own — everything it needs, it contains. Nothing in `docs/` can
be cited by reference, because `docs/` is deleted before submission.

---

## 1. The two contests this report serves

### Arduino Physical AI Challenge India 2026 (robu.in + Arduino + Qualcomm)

- **Deadline:** 23 Aug 2026 (user-confirmed; the public page's 31 Jul is stale).
- **Track:** Industrial & Sustainability AI.
- **Rubric, 100 pts:** Functionality & Execution 40 · Innovation & Originality 25
  · Technical Documentation (BOM, schematics, code quality) 20 · Presentation &
  Creativity 15. **Open source earns bonus points.**
- **Deliverables:** demo video (continuous, unedited, publicly accessible) ·
  GitHub source · report PDF · circuit/system diagram · **proof of purchase of
  the UNO Q (mandatory)**.

### Invent the Future with Arduino UNO Q and App Lab (Hackster.io)

Fetched from the live rules page 2026-08-02. Sponsors: Arduino, Qualcomm and
**Edge Impulse**; also Foundries, HuggingFace, SparkFun, Seeed, Farnell, ST.
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

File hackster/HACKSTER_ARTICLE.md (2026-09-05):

# 1 Predictive Maintenance, Built for a Different Scale

# 1.1 The Limits of Manual Inspection

"Twenty-two years. Eleven machines, six people, and I'm out on the floor with them most days." Ravi wiped his hands on a rag. "I know the pulse of every machine in here. Hand on the housing, that's all it takes."

He looked out over the floor.
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

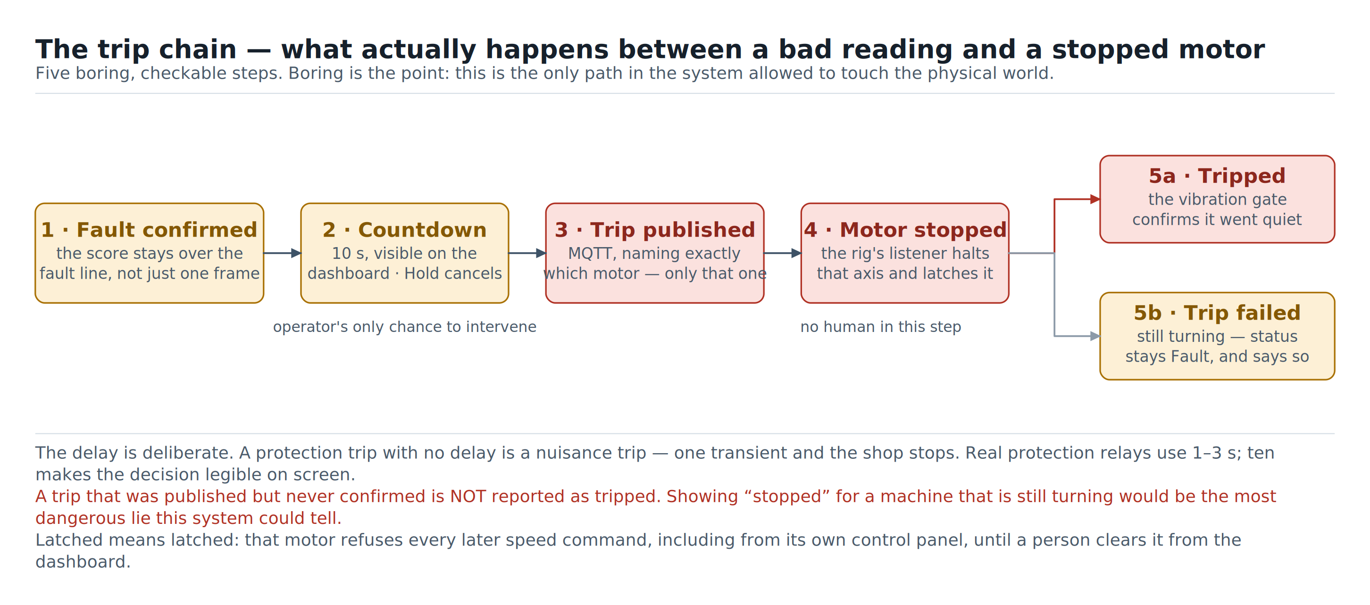
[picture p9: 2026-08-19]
report/diagrams/07-trip-sequence.png

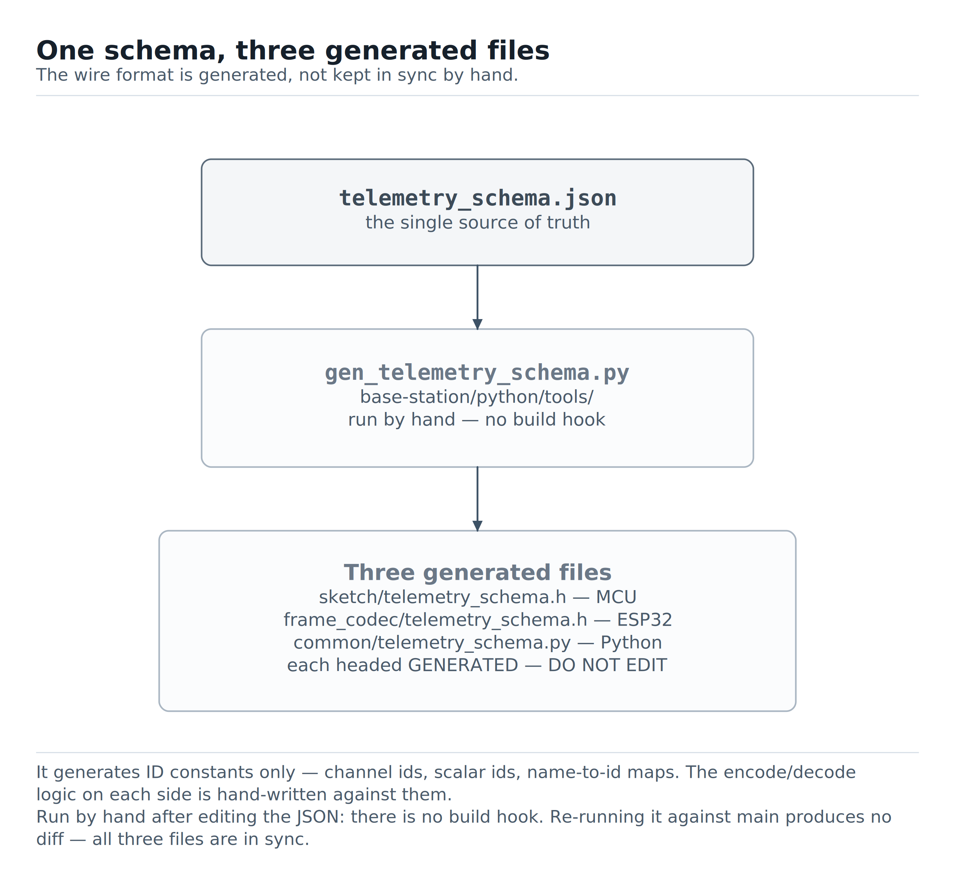
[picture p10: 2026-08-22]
report/diagrams/15b-wire-format.png

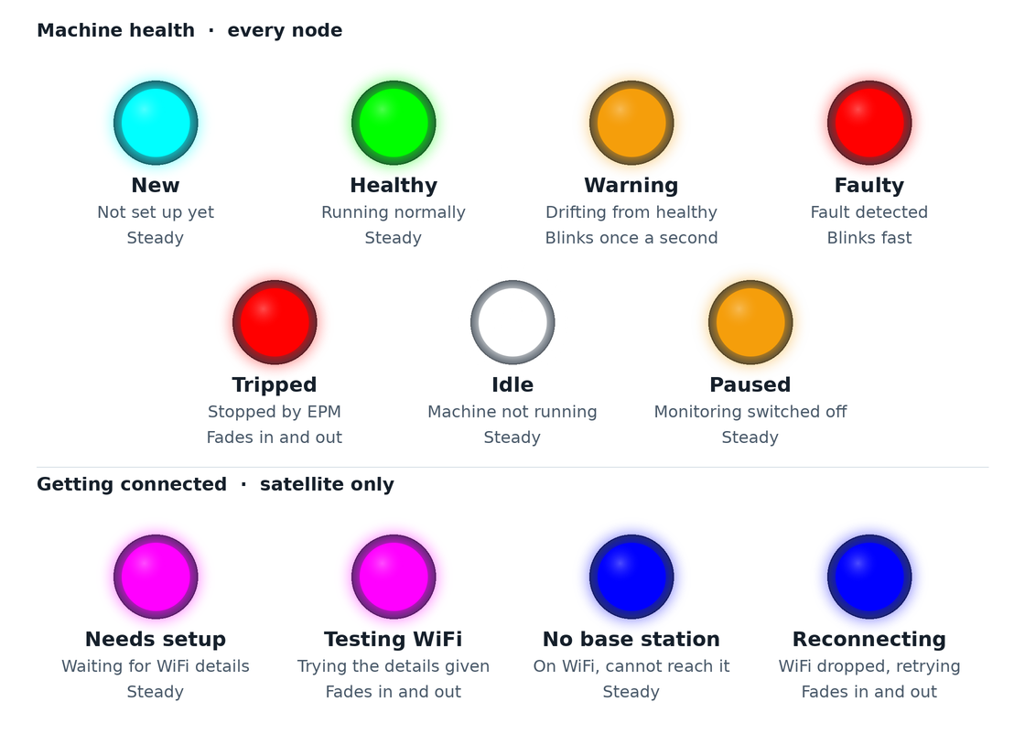
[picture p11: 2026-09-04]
report/diagrams/18-status-light.png

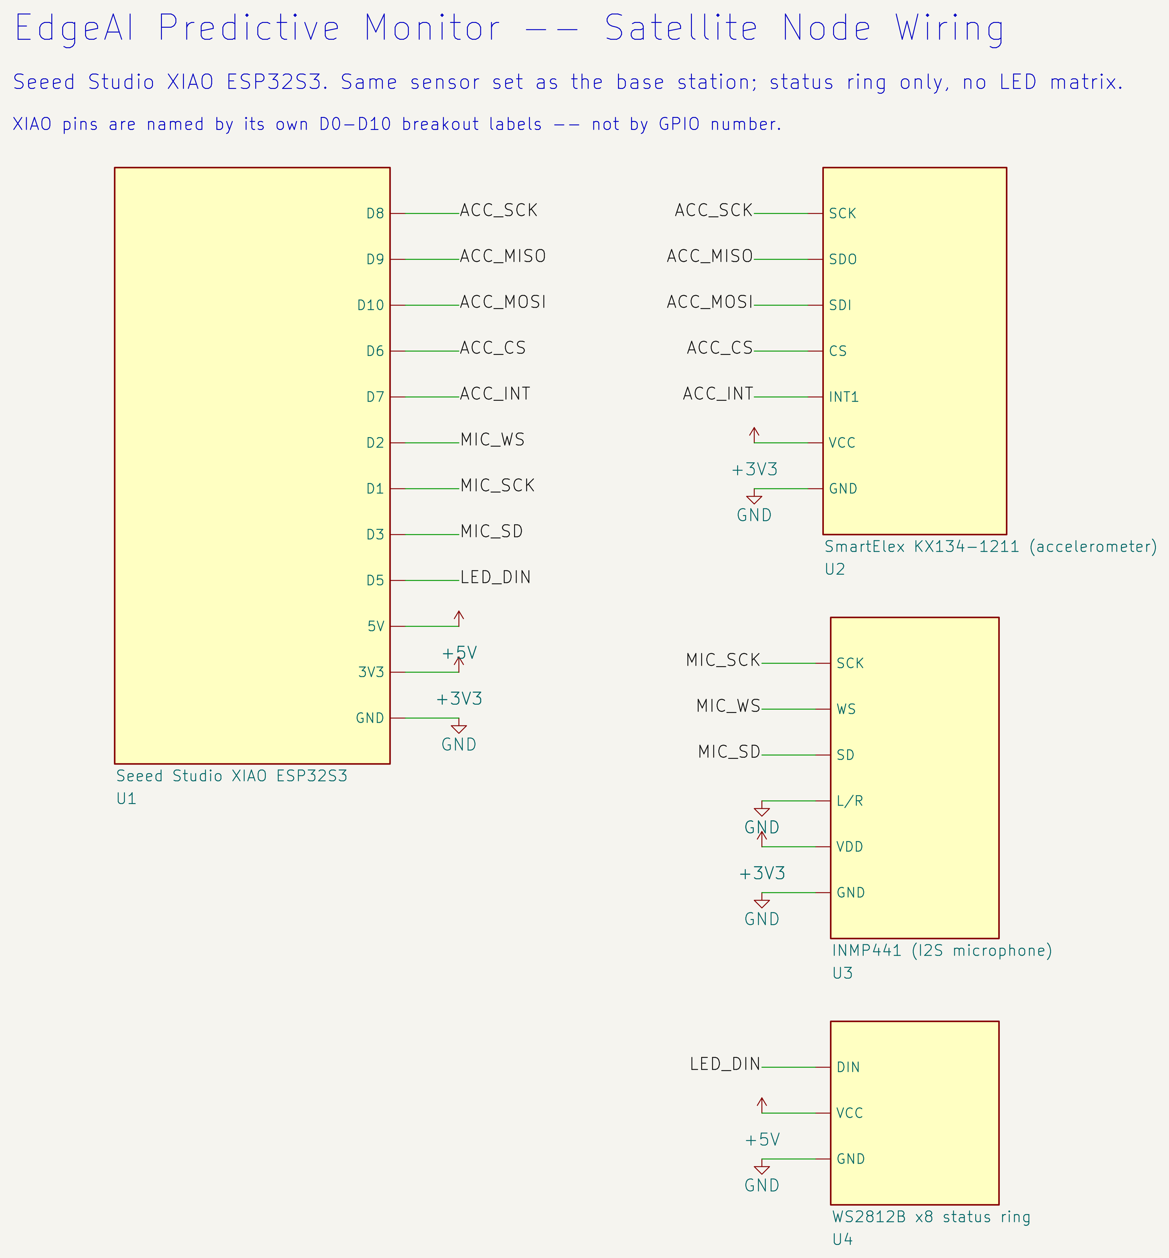
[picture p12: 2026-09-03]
report/diagrams/03b-satellite-node-schematic-kicad.png

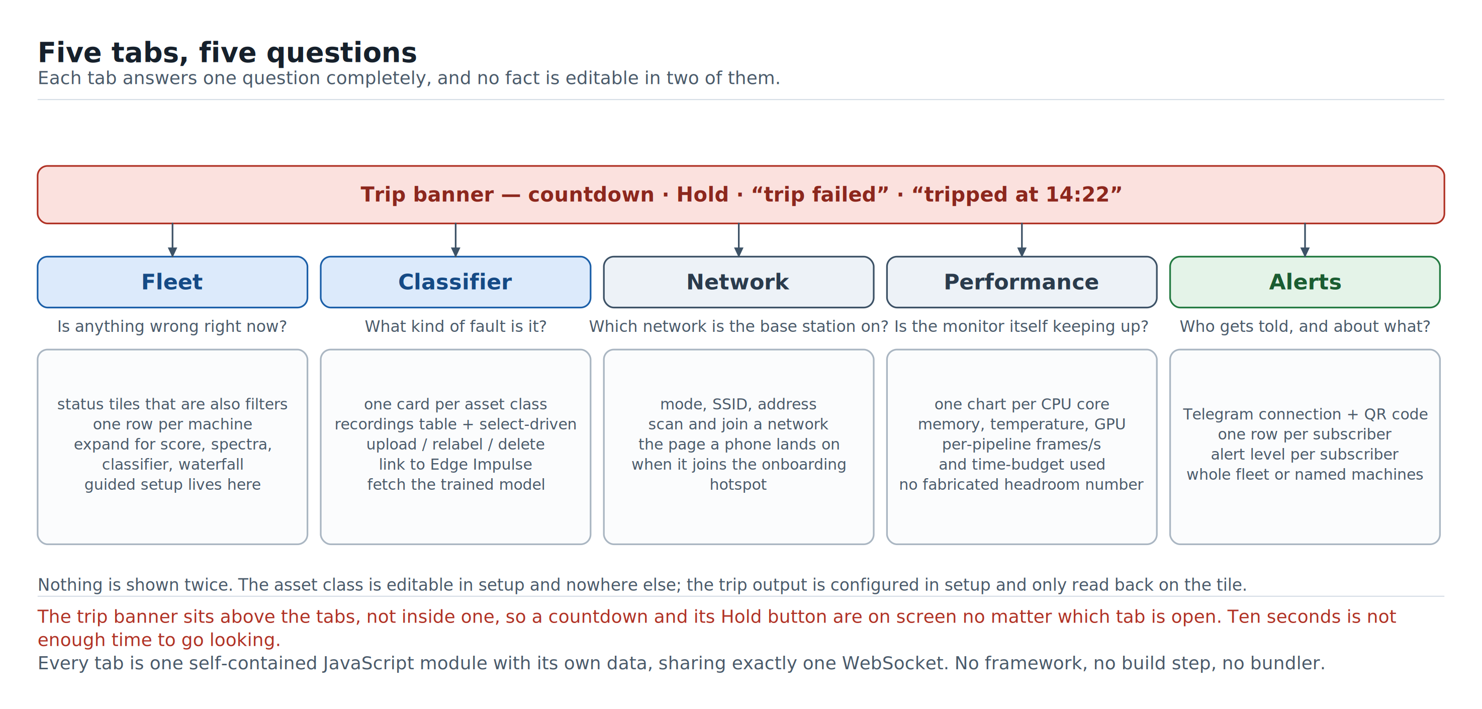
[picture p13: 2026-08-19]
report/diagrams/13-dashboard-tabs.png

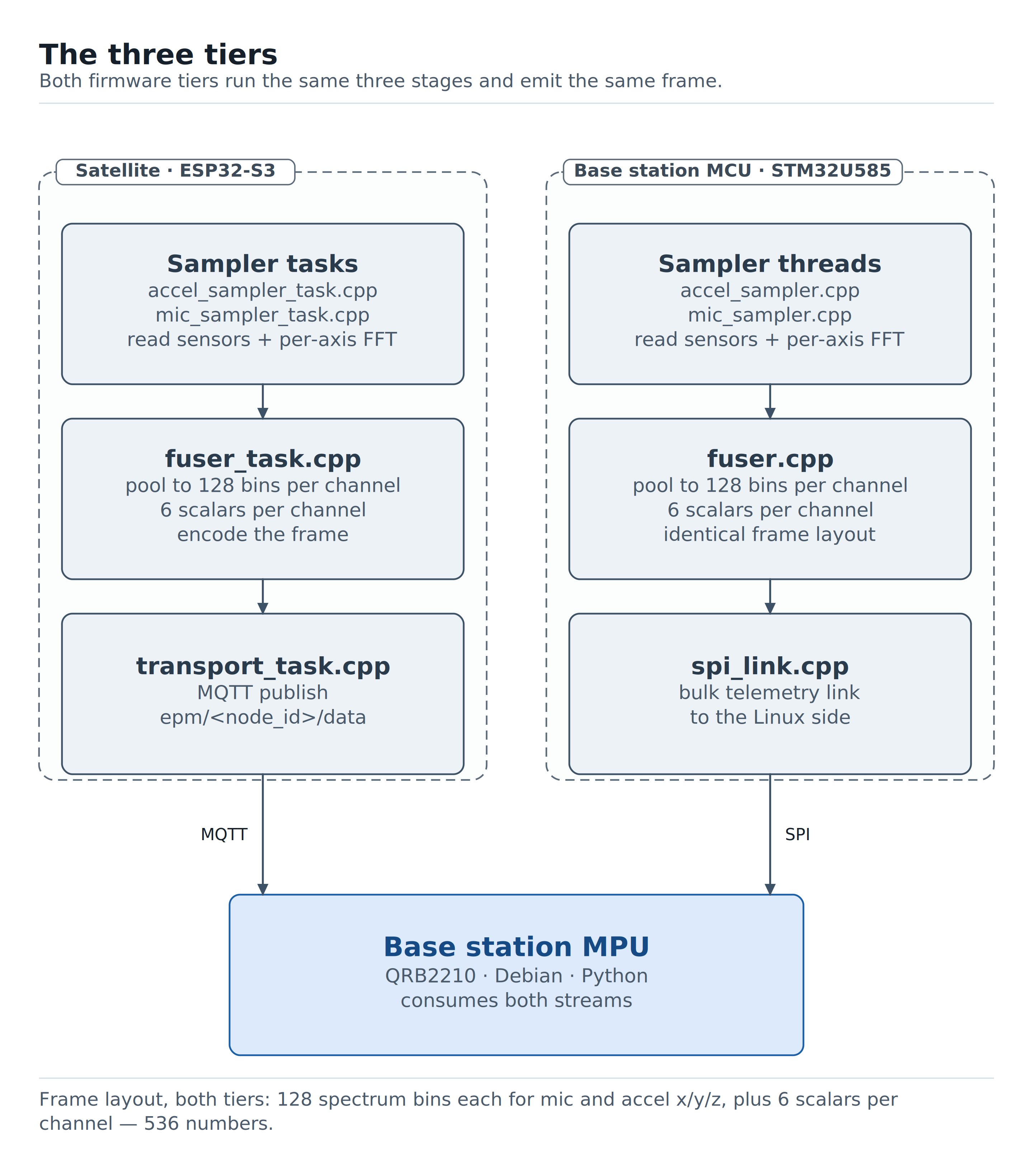
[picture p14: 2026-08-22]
report/diagrams/15a-tiers.png

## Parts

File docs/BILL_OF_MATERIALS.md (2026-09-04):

# Bill of Materials

Everything you need to buy to build an EdgeAI Predictive Monitor.

**This is the canonical parts list for the project.** Anywhere else a part is
mentioned, including the Hackster write-up, this file is the one that is right.

Build steps that use these parts are in [`BUILD_GUIDE.md`](BUILD_GUIDE.md).
Pin-by-pin wiring is in [`BUILD_GUIDE.md` §4.1 and §5.1](BUILD_GUIDE.md).

---

## 0. How much to buy

The system is one **base station** plus one **satellite node** per additional
machine. Buy in blocks:

| You want to monitor | Buy | Section |
|---|---|---|
| 1 machine | Base station | [§1](#1-base-station-one-per-site) |
| N machines | Base station + (N−1) satellites | [§1](#1-base-station-one-per-site) + [§2](#2-satellite-node-one-per-extra-machine) |
| Nothing yet, just want to see it run | Nothing at all | [`BUILD_GUIDE.md` §8](BUILD_GUIDE.md) |

The motor test rig in [§3](#3-motor-test-rig-validation-only) is **not part of a
deployment**. It is the bench setup used to induce and measure faults, and you
only need it if you are reproducing the project's results.

Every block also draws on the shared consumables in
[§4](#4-shared-consumables) and the printed parts in
[§5](#5-3d-printed-parts).

---

## 1. Base station, one per site

The central node. It senses its own machine, runs the models for every node in
the fleet, serves the dashboard and sends the alerts.

| Part | Qty | What it does here | Buy |
|---|---:|---|---|
| Arduino UNO Q, 4 GB (ABX00173) | 1 | The board. Real-time sensing on the STM32U585, models and dashboard on the Linux side | [Robu][unoq] |
| KX134-1211 SPI accelerometer | 1 | Vibration sensing to 6 kHz | [Robu][kx134] |
| INMP441 I2S MEMS microphone | 1 | Audio sensing to 24 kHz | [Robu][inmp441] |
| WS2812B 8-pixel RGB ring | 1 | The status light on top of the pod | [Robu][ws2812] |
| 9 W LED bulb | 1 | Bought for its diffuser cap, which becomes the status dome over the ring | [Amazon][bulb] |
| Fresnel lens, credit-card size | 1 | Magnifies the UNO Q's onboard LED matrix so the fleet summary is readable across a room | [Amazon][fresnel] |
| Neodymium ring magnet, N51, OD15 × ID7 × 5 mm | 1 | Couples the pod to the machine housing | [Patel Magnets][magnet] |
| JST-XH 2.54 connector, 8-pin, male and female | 2 | Board-to-harness connectors | [Maker Bazar][jst8] |
| JST-XH 2.54 connector, 6-pin, male and female | 1 | Accelerometer harness | [Maker Bazar][jst6] |
| JST-XH 2.54 connector, 4-pin, male and female | 1 | Microphone harness | [Maker Bazar][jst4] |
| JST-XH 2.54 connector, 3-pin, male and female | 3 | Status ring and power harnesses | [Maker Bazar][jst3] |
| JST-XH 2.54 connector, 2-pin, male and female | 1 | Power harness | [Maker Bazar][jst2] |
| USB-C cable | 1 | Power and the App Lab link | [Amazon][usbc] |

**The mount is not an accessory.** An accelerometer read through a soft or loose
mount is a low-pass filter you did not ask for, and it removes exactly the
high-frequency content that early bearing faults live in. Rigid coupling to the
machine housing, as close to the bearing as the geometry allows, matters more
than the price tag suggests.

A 2 GB UNO Q variant exists and is a straight drop-in. Nothing in this project
needs 4 GB, but 4 GB is the one to buy if you plan to train larger models
on-device.

---

## 2. Satellite node, one per extra machine

Same three sensing parts as the base station, on a XIAO ESP32-S3 instead. It
watches its own machine and reports to the base station over Wi-Fi.

Quantities below are **per node**.

| Part | Qty | What it does here | Buy |
|---|---:|---|---|
| Seeed Studio XIAO ESP32-S3 | 1 | The node's brain. Wi-Fi built in, no separate radio | [Robu][xiao] |
| KX134-1211 SPI accelerometer | 1 | Vibration sensing, same part as the base station | [Robu][kx134] |
| INMP441 I2S MEMS microphone | 1 | Audio sensing, same part as the base station | [Robu][inmp441] |
| WS2812B 8-pixel RGB ring | 1 | Status light, same part as the base station | [Robu][ws2812] |
| 9 W LED bulb | 1 | Diffuser cap for the status dome | [Amazon][bulb] |
| Neodymium ring magnet, N51, OD15 × ID7 × 5 mm | 1 | Couples the pod to the machine housing | [Patel Magnets][magnet] |
| JST-XH 2.54 connector, 6-pin, male and female | 3 | Sensor harnesses | [Maker Bazar][jst6] |
| JST-XH 2.54 connector, 4-pin, male and female | 1 | Microphone harness | [Maker Bazar][jst4] |
| JST-XH 2.54 connector, 3-pin, male and female | 2 | Status ring and power harnesses | [Maker Bazar][jst3] |
| USB-C cable | 1 | Power, and flashing over USB | [Amazon][usbc] |

Three of the four sensing parts are identical to the base station's on purpose:
one line item to buy in bulk, not a different parts list per machine. That is
also what keeps the cost of expanding the fleet close to linear.

A satellite has no Fresnel lens, because it has no LED matrix. Its printed bezel
has no lens window either.

---

## 3. Motor test rig, validation only

Not part of a deployment. This is the bench setup used to induce repeatable
faults and measure the trip.

| Part | Qty | What it does here | Buy |
|---|---:|---|---|
| Arduino Uno R3 | 1 | Motor controller. Receives stop commands, drives step pulses | [Robu][uno] |
| CNC Shield V3 | 1 | Driver carrier board | [Robu][cncshield] |
| A4988 stepper driver (or DRV8825) | 3 | One per motor axis | [Robu][a4988] |
| NEMA-17 stepper motor, JK42HS48 | 3 | The "machines" being monitored on the bench | [Robu][nema17] |
| 12 to 24 V DC power supply, at least 3 A | 1 | Motor power | [Robu][psu] |
| Bearing, 6201 | 2 | Pump rig | [Misumi][bearing6201] |
| Bearing, 6004 | 1 | Turbine rig | [Misumi][bearing6004] |
| M6 × 18 mm nut and bolt | 51 | Flywheel mass, and magnetic mounting of sensor nodes to the rig | any hardware shop |
| Wooden block, 200 × 100 × 20 mm | 3 | Motor rig base | any hardware shop |

The bolts are the fault-injection mechanism as much as they are fasteners: they
bolt into the flywheel's bolt circle, and moving or removing one produces a
repeatable imbalance.

---

## 4. Shared consumables

Bought once, used across every block above.

| Part | Qty | What it does here | Buy |
|---|---:|---|---|
| eSUN PLA+ Silver, 1.75 mm spool | 1 | Node enclosure shells and mount kits | [Robu][pla-silver] |
| eSUN PLA+ Orange, 1.75 mm spool | 1 | Node front bezels | [Robu][pla-orange] |
| eSUN PLA+ Grey, 1.75 mm spool | 2 | Motor rig brackets and flywheel | [Robu][pla-grey] |
| eSUN PLA+ Gold, 1.75 mm spool | 1 | Motor rig rings, pulley and shaft | [Robu][pla-gold] |
| Multicolor flat ribbon cable, 10-wire, 1 m | 1 | Every sensor harness | [Robu][ribbon] |
| 2515 JST-XH crimp terminal, female pins | ~100 | The harness ends | [Maker Bazar][crimp] |

Colours are what this build used, not a requirement. Any PLA works.

---

## 5. 3D-printed parts

All models are in [`3d-models/`](../3d-models/), each supplied as both **3MF**
(plated and ready to slice, colour already assigned) and **STL** (plain mesh).
Thirteen parts in total. `a` is the base station, `b` is the satellite, `c` is
the validation rig.

| File | Contains | Colour | Needed for |
|---|---|---|---|
| `a1_base_station_silver` | Shell, front and back halves | Silver | Base station |
| `a2_base_station_silver` | Mount kit: left and right plates, leg, two stem connectors | Silver | Base station |
| `a3_base_station_orange` | Front bezel: left and right rims, lens insert, foot | Orange | Base station |
| `b1_satellite_silver` | Shell, front and back halves | Silver | Each satellite |
| `b2_satellite_silver` | Mount kit, same pattern as the base station's | Silver | Each satellite |
| `b3_satellite_orange` | Front bezel: left and right rims, foot. No lens insert | Orange | Each satellite |
| `c1_belt_drive_rig_grey` | Upright L-bracket with bearing bore | Grey | Belt-drive rig |
| `c2_belt_drive_rig_gold` | Two bearing rings and a stepper ring | Gold | Belt-drive rig |
| `c3_belt_drive_rig_gold` | Toothed pulley, hex shaft, bearing holder | Gold | Belt-drive rig |
| `c6_direct_drive_rig_grey` | U-shaped pillow-block bracket | Grey | Direct-drive rig |
| `c7_direct_drive_rig_gold` | Two bearing rings, stepper ring, coupling shaft | Gold | Direct-drive rig |
| `c4_fly_wheel_grey` | Rotor disc | Grey | Both rigs |
| `c5_fly_wheel_ring_gold` | Bolt-on ring | Gold | Both rigs |

**For a deployment you only print `a1`–`a3` once, and `b1`–`b3` per satellite.**
The `c` parts are the bench rig. Pick belt-drive or direct-drive, then add the
shared flywheel either way.

The optional embossed wordmark for the shell faces is in
[`hardware/enclosure-logo/`](../hardware/enclosure-logo/), with its own README
covering slicer settings.

Print settings, the per-plate part breakdown and assembly order are in
[`3d-models/README.md`](../3d-models/README.md) and
[`BUILD_GUIDE.md` §2](BUILD_GUIDE.md).

---

## 6. Software and tools

The other half of a bill of materials. Everything here is free unless marked.

| | What | Used for | Cost |
|---|---|---|---|
| **On the board** | Debian Linux (QRB2210) and Zephyr RTOS (STM32U585) | Both operating systems, both shipped with the UNO Q | free |
| | Python 3, FastAPI, `websockets` | The application and the dashboard's live feed | free |
| | PyTorch | Training and running the per-machine autoencoder, on-device | free |
| | `ai-edge-litert` (TFLite) | Running the fetched fault classifier on CPU | free |
| | Mosquitto | The MQTT broker, hosted on the UNO Q itself | free |
| **Cloud** | Edge Impulse | Training the fault classifier, one project per asset class | free tier is enough |
| | Telegram Bot API | Phone alerts | free |
| **Development** | Arduino App Lab | Building, deploying and running both halves. Also the only place to set brick secrets | free |
| | PlatformIO | Satellite (ESP32-S3) and motor-rig (Uno) firmware | free |
| | KiCad 9 | The three schematics in [`hardware/kicad/`](../hardware/kicad/) | free |
| | A slicer (PrusaSlicer, OrcaSlicer, Bambu Studio) | The printed parts | free |
| | `adb`, `usbipd` | Getting onto the board from a Windows or WSL host | free |
| **Hardware tools** | Crimping tool for JST-XH, wire cutters, small screwdriver set | Harnesses, and setting each stepper driver's current limit | — |
| | Multimeter | Setting the driver reference voltage on the rig | — |
| | Soldering iron | Headers on the sensor breakouts | — |
| | 3D printer, 0.4 mm nozzle | The enclosures and rig parts | — |
| | USB-UART adapter | Optional: the STM32's separate debug console | low |

**Nothing in the production path needs a paid service.** Edge Impulse's free
tier covers the classifier work, and the anomaly detection, which is the part
that decides whether a machine stops, runs entirely on the board with no account
of any kind.

---

## 7. What it costs

| Scenario | Parts | Roughly |
|---|---|---|
| 1 machine monitored | Base station | $100 |
| 3 machines monitored | Base station + 2 satellites | $150 |
| 10 machines monitored | Base station + 9 satellites | $325 |

Electronics only. Filament, printer time and the validation rig are not counted,
and neither is the crimp and connector stock, which is bought in bulk and lasts
many nodes.

For context, a single unplanned bearing failure on a small CNC lathe, counting
parts, labour and two weeks of lost capacity, comfortably exceeds the ten-machine
figure.

---

## 8. Notes on substitutions

- **The accelerometer is the one part not to swap casually.** The KX134-1211 was
  chosen for two reasons: it reaches 6 kHz, which is where early bearing faults
  show up, and it has a 512-byte hardware FIFO. Without that FIFO the
  microcontroller needs servicing roughly every 39 microseconds at full rate,
  which is a hostile interrupt load for a chip that also has FFTs to run.
  Cheaper parts fail the first test; far more expensive ones buy accuracy this
  application cannot use.
- **The microphone can be any I2S MEMS part** with a 24-bit output, but the
  INMP441's pinout is what the printed shell's cutout matches.
- **DRV8825 drivers work in place of A4988** on the rig, with a different
  current-limit formula. See [`BUILD_GUIDE.md` §7](BUILD_GUIDE.md).
- **The 9 W bulb is a diffuser, not a light.** Any frosted dome of about the
  same diameter does the same job. Nothing electrical in the bulb is used.
- Links are to Indian retailers, checked in August 2026. Prices in this category
  move, so confirm at the time of purchase.

---

<!-- Purchase links. Kept out of the tables so the tables stay readable. -->

[unoq]: https://robu.in/product/official-arduino-uno-q-4gb-single-board-computer-abx00173/
[kx134]: https://robu.in/product/smartelex-triple-axis-accelerometer-breakout-kx134/
[inmp441]: https://robu.in/product/inmp441-mems-high-precision-omnidirectional-microphone-module-i2s/
[ws2812]: https://robu.in/product/8bit-ws2812-5050-rgb-led-built-full-color-driving-lights-circular-development-board/
[bulb]: https://www.amazon.in/Crompton-Dyna-Round-Cool-Light/dp/B0B6FJNH97/
[fresnel]: https://www.amazon.in/oddpodTM-Fresnel-Flexible-Plastic-Magnifying/dp/B09MDH1LLH/
[magnet]: https://patelmagnets.com/shop/od15-x-id7-x-5mm-neodymium-magnet/
[usbc]: https://www.amazon.in/Ambrane-Unbreakable-Charging-Braided-Cable/dp/B098NS6PVG/
[xiao]: https://robu.in/product/seeed-studio-xiao-esp32s3-2-4ghz-wifi-ble-5-0/
[jst8]: https://makerbazar.in/products/male-female-connector-straight?variant=46140555493616
[jst6]: https://makerbazar.in/products/male-female-connector-straight?variant=46137886703856
[jst4]: https://makerbazar.in/products/male-female-connector-straight?variant=46134456320240
[jst3]: https://makerbazar.in/products/male-female-connector-straight?variant=46134287663344
[jst2]: https://makerbazar.in/products/male-female-connector-straight?variant=46134287630576
[crimp]: https://makerbazar.in/products/2515-jst-xh-crimp-terminal-female-pins
[ribbon]: https://robu.in/product/multicolor-flat-ribbon-cable-10-cond-1meter/
[uno]: https://robu.in/product/arduino-uno-r3/
[cncshield]: https://robu.in/product/cnc-shield-v3-engraving-machine-3d-printer-a4988-drv8825-driver-expansion-board/
[a4988]: https://robu.in/product/a4988-driver-stepper-motor-driver/
[nema17]: https://robu.in/product/nema17-4-2-kgcm-stepper-motor/
[psu]: https://robu.in/product/mean-well-lrs-150-12-12v-12-5a-150w-smps/
[bearing6201]: https://in.misumi-ec.com/vona2/detail/110310367019/?HissuCode=C-E6201ZZ
[bearing6004]: https://in.misumi-ec.com/vona2/detail/110310367019/?HissuCode=C-E6004ZZ
[pla-silver]: https://robu.in/product/esun-pla-1-75mm-3d-printing-filament-1kg-silver/
[pla-orange]: https://robu.in/product/esun-pla-1-75mm-3d-printing-filament-1kg-orange/
[pla-grey]: https://robu.in/product/esun-pla-1-75mm-3d-printing-filament-1kg-grey/
[pla-gold]: https://robu.in/product/esun-pla-1-75mm-3d-printing-filament-1kg-gold/

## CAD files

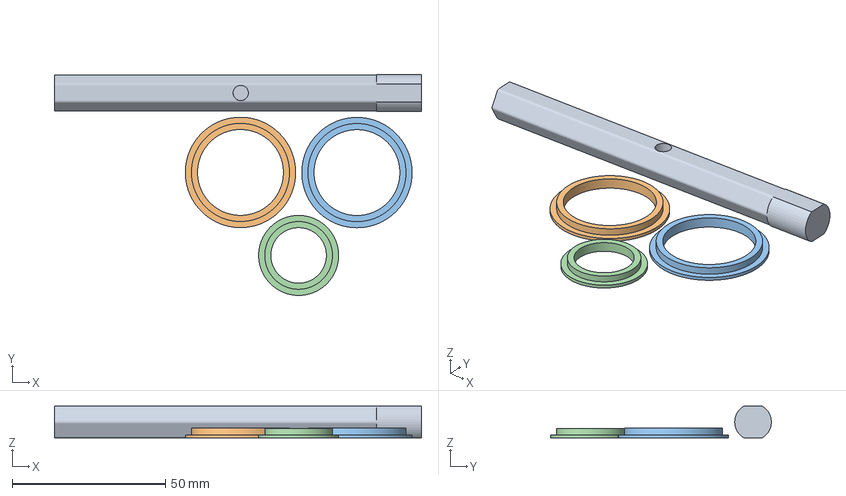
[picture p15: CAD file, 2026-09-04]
3d-models/c7_direct_drive_rig_gold.3mf
119.7 x 72.0 x 10.4 mm
shaft
bearing_ring_2
bearing_ring_1
stepper_ring

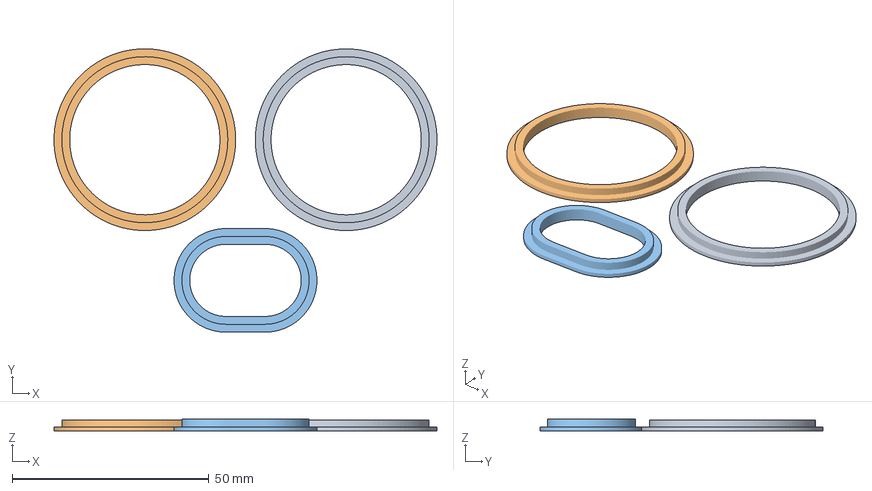
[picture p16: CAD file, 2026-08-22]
3d-models/c2_belt_drive_rig_gold.3mf
97.3 x 71.9 x 3.00 mm
bearing_ring_1
bearing_ring_2
stepper_ring

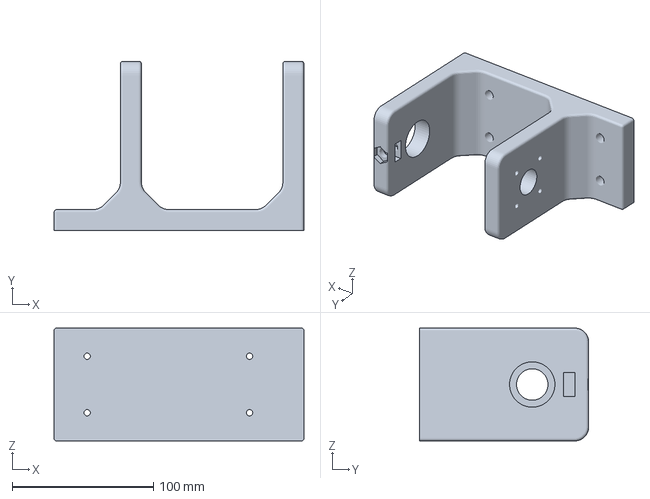
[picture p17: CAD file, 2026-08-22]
3d-models/c6_direct_drive_rig_grey.3mf
177.0 x 120.0 x 80.0 mm

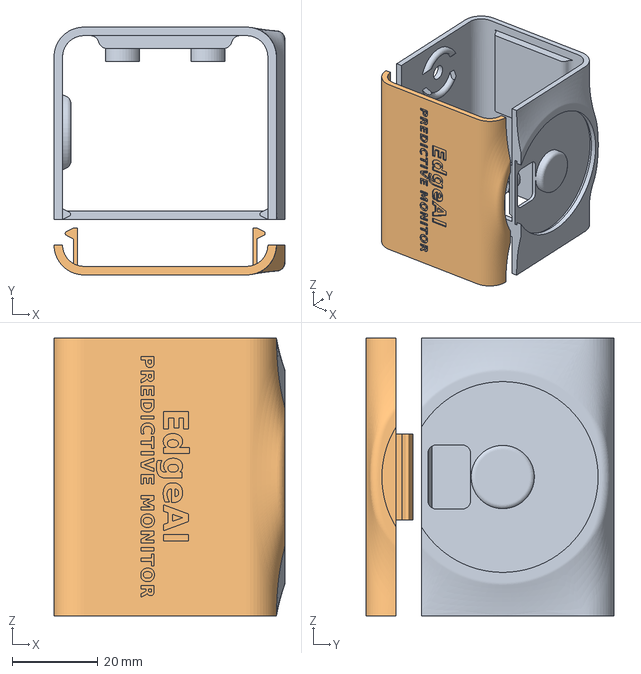
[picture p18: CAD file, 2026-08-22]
3d-models/b1_satellite_silver.3mf
54.0 x 57.9 x 65.0 mm
main_back
main_front

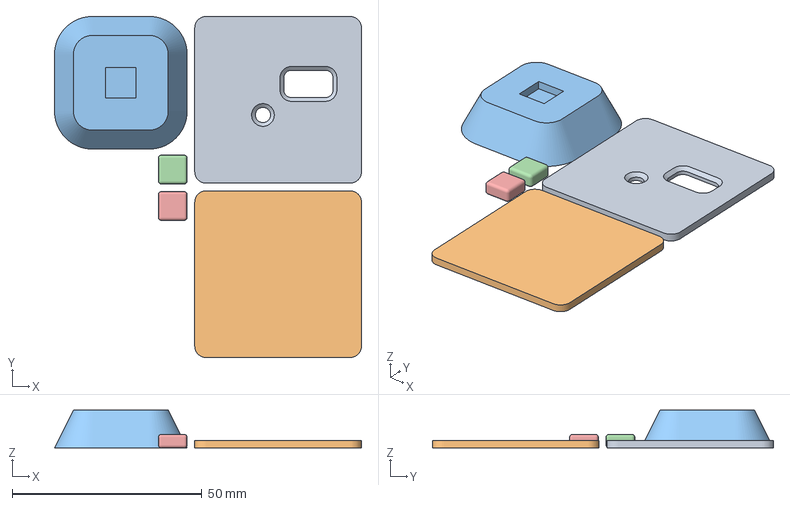
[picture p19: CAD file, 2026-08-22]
3d-models/b2_satellite_silver.3mf
81.0 x 90.0 x 10.0 mm
left_plate
right_plate
leg
stem_connector_2
stem_connector_1

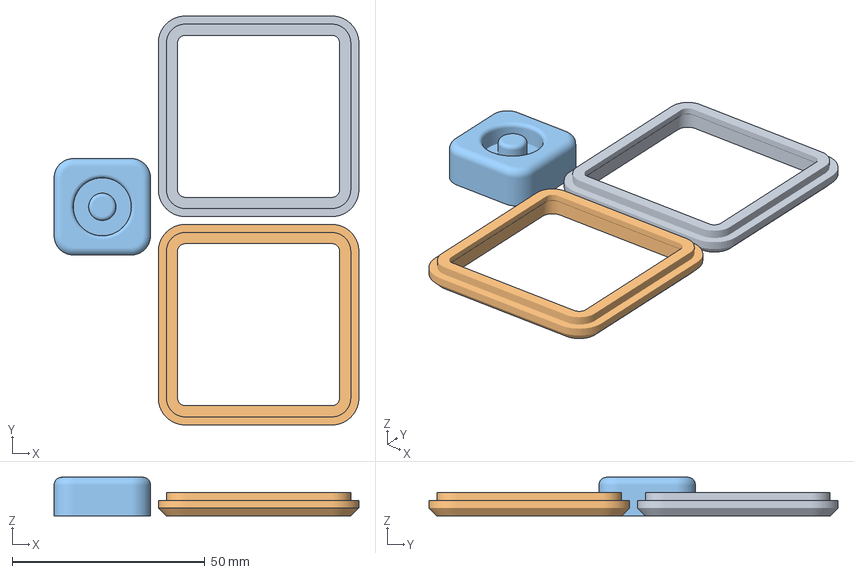
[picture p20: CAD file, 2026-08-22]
3d-models/b3_satellite_orange.3mf
79.0 x 106.0 x 10.0 mm
left_rim
right_rim
foot

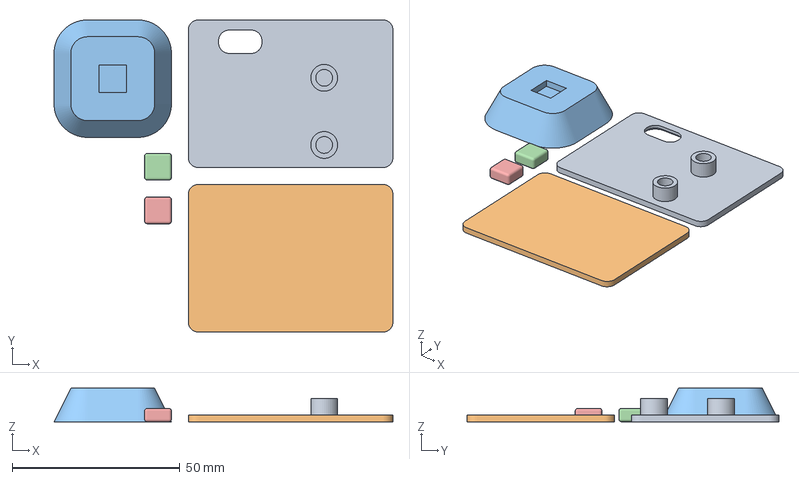
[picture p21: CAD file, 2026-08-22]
3d-models/a2_base_station_silver.3mf
101.0 x 93.0 x 10.0 mm
left_plate
right_plate
leg
stem_connector_2
stem_connector_1

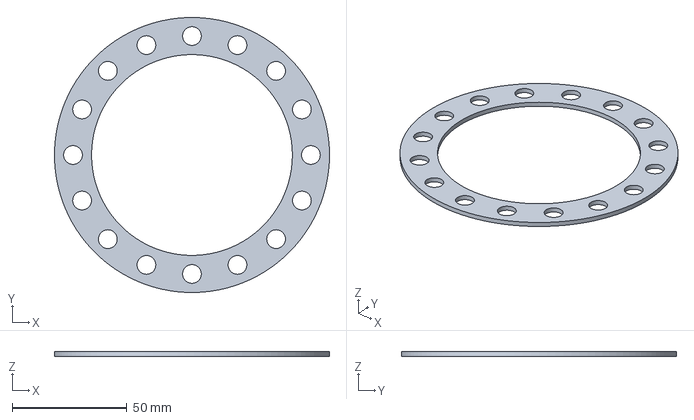
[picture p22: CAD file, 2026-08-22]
3d-models/c5_fly_wheel_ring_gold.3mf
120.0 x 120.0 x 2.00 mm

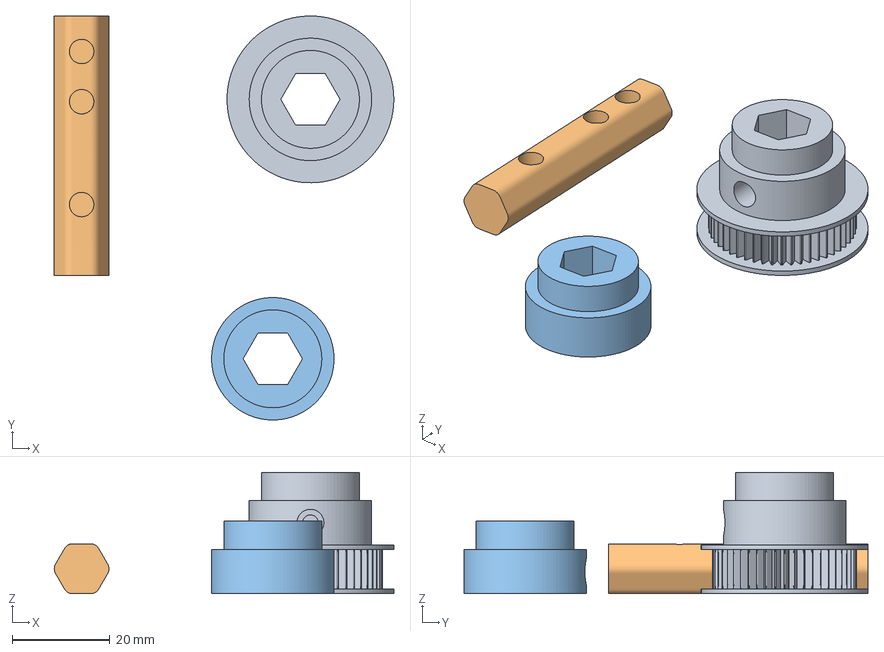
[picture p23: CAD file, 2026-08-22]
3d-models/c3_belt_drive_rig_gold.3mf
69.3 x 82.5 x 24.8 mm
pulley
shaft
bearing_holder

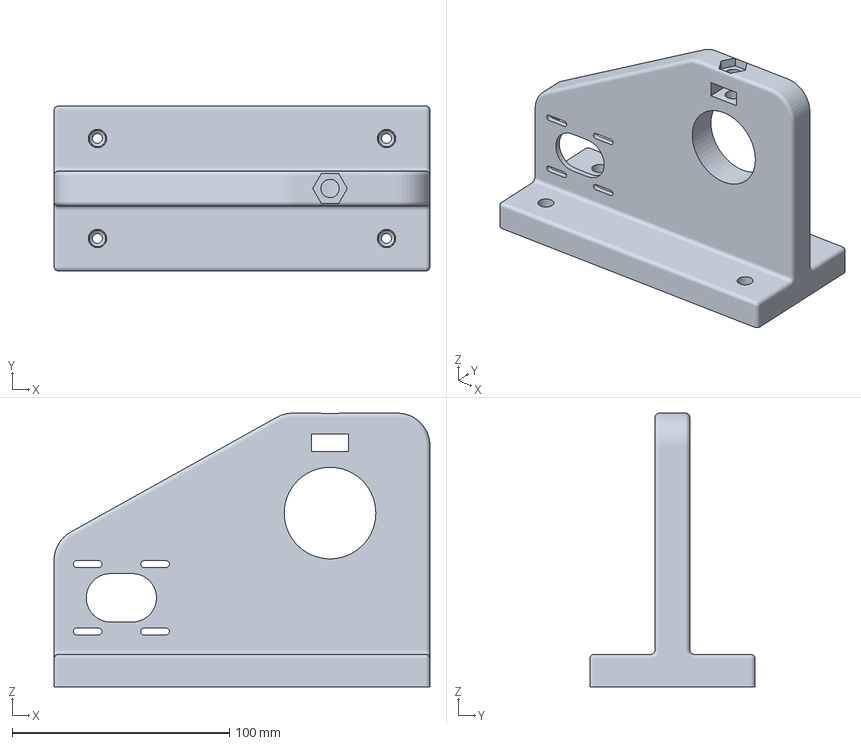
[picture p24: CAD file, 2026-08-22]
3d-models/c1_belt_drive_rig_grey.3mf
173.0 x 76.0 x 126.0 mm

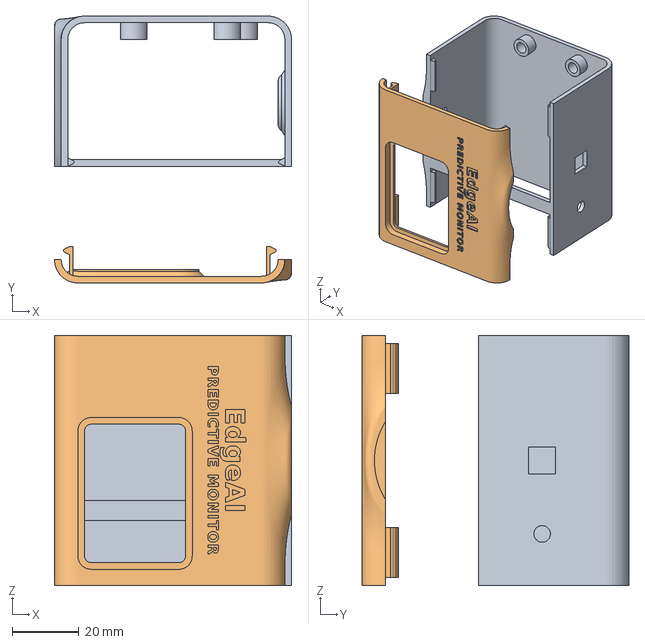
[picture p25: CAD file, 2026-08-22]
3d-models/a1_base_station_silver.3mf
71.0 x 79.9 x 75.0 mm
main_back
main_front

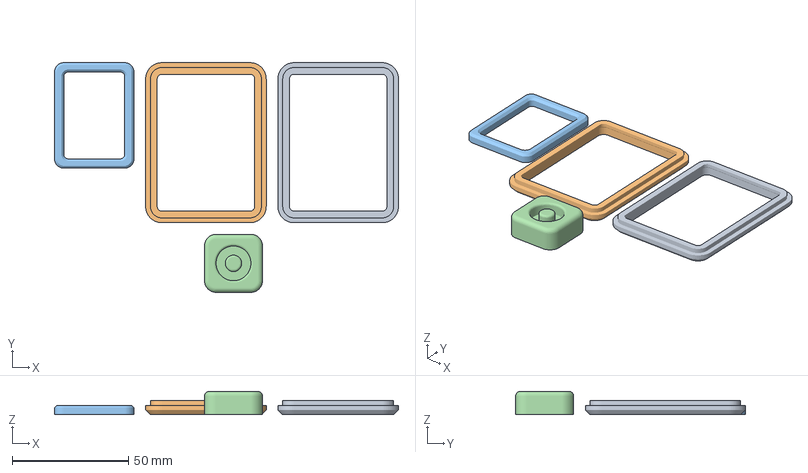
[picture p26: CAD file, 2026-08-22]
3d-models/a3_base_station_orange.3mf
148.3 x 99.0 x 10.0 mm
left_rim
right_rim
lens
foot

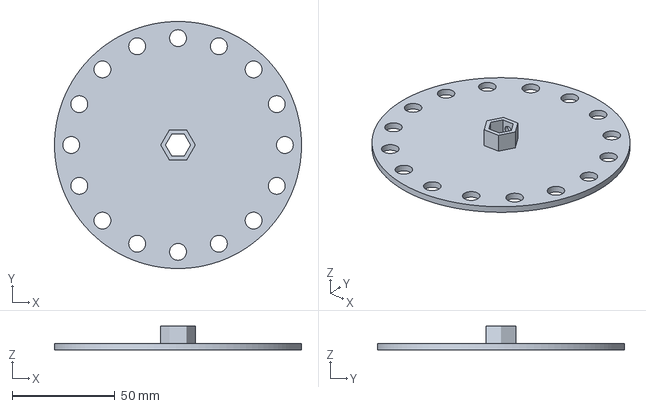
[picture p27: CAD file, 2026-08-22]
3d-models/c4_fly_wheel_grey.3mf
120.0 x 120.0 x 11.5 mm

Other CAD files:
3d-models/a1_base_station_silver.stl
3d-models/a2_base_station_silver.stl
3d-models/a3_base_station_orange.stl
3d-models/b1_satellite_silver.stl
3d-models/b2_satellite_silver.stl
3d-models/b3_satellite_orange.stl
3d-models/c1_belt_drive_rig_grey.stl
3d-models/c2_belt_drive_rig_gold.stl
3d-models/c3_belt_drive_rig_gold.stl
3d-models/c4_fly_wheel_grey.stl
3d-models/c5_fly_wheel_ring_gold.stl
3d-models/c6_direct_drive_rig_grey.stl
3d-models/c7_direct_drive_rig_gold.stl

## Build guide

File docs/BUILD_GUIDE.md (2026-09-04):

# Build Guide

How to build an EdgeAI Predictive Monitor, from an empty bench to a machine that
is being watched.

Parts and buy links are in [`BILL_OF_MATERIALS.md`](BILL_OF_MATERIALS.md). This
guide assumes you have them.

---

## 0. Pick your path

There are five ways in, and **two of them need no hardware at all**. Those two
are the fastest way to see the whole system working, and the right place to
start if you are still deciding whether to buy anything.

| Path | Hardware needed | Time | Good for |
|---|---|---|---|
| [§8.1 Desktop dashboard + simulated node](#81-no-hardware-at-all) | none | ~10 min | Seeing the entire dashboard, setup, scoring and classifier flow on a laptop |
| [§8.2 Simulated node against a real base station](#82-a-simulated-node-against-a-real-base-station) | UNO Q only | ~30 min | Testing the real device's ingestion and fleet handling without building satellites |
| [§4 Base station](#4-build-the-base-station) | UNO Q + sensors | ~2 hours | The real thing, one machine |
| [§5 Satellite node](#5-build-a-satellite-node) | XIAO ESP32-S3 + sensors | ~1 hour | Adding machines |
| [§7 Motor test rig](#7-optional-the-motor-test-rig) | Uno + CNC shield + steppers | ~2 hours | Reproducing the project's measurements and the trip |

**If you are starting from nothing, do §8.1 first.** It takes ten minutes, needs
no purchase, and everything you learn about the dashboard there is true of the
real device.

Add the printed enclosure ([§2](#2-print-the-enclosure)) and harnesses
([§3](#3-make-the-harnesses)) to the times above if you are building the pods
properly rather than working on a bench with jumper wires.

---

## 1. Before you start

Get the repo:

```sh
git clone https://github.com/rahuljeyaraj/edgeai-predictive-monitor.git
cd edgeai-predictive-monitor
```

Install, in whatever order suits you:

- **Arduino App Lab**, for the UNO Q. This is the only tool that can flash the
  STM32 side and the only place brick secrets can be set.
- **PlatformIO**, for the satellite and the motor rig.
- **A slicer**, for the printed parts.

Tools on the bench: a JST-XH crimping tool, wire cutters, a soldering iron for
the breakout headers, and a multimeter if you are building the rig.

---

## 2. Print the enclosure

Models are in [`3d-models/`](../3d-models/), thirteen parts, each as a **3MF**
(plated and ready to slice, colour already assigned) and an **STL**. Print the
3MF unless you have a reason not to. The file-by-file map is in
[`3d-models/README.md`](../3d-models/README.md).

For one base station, print `a1`, `a2` and `a3`. For each satellite, print `b1`,
`b2` and `b3`. That is all a deployment needs; the `c` parts are the bench rig
([§7](#7-optional-the-motor-test-rig)).

Settings that worked here:

| | |
|---|---|
| Material | PLA+ |
| Nozzle | 0.4 mm |
| Layer height | 0.2 mm |
| Infill | 20% for shells and bezels, 40% or more for the rig brackets and flywheel |
| Supports | none needed; the plates are already oriented |

Each pod is three sub-assemblies:

- **Shell**, front and back halves that snap together around the board.
- **Mount kit**, two backplates plus a leg and two stem connectors, which is what
  actually holds the pod on the machine.
- **Front bezel**, two rims and a foot. The base station's bezel also has a lens
  insert, which holds the Fresnel lens over the UNO Q's LED matrix. The
  satellite's does not, because a satellite has no matrix.

Optional: emboss the wordmark on the shell face before slicing. The SVGs and the
slicer settings are in [`hardware/enclosure-logo/`](../hardware/enclosure-logo/).
Engrave it recessed at 0.3 to 0.4 mm, not raised.

---

## 3. Make the harnesses

Every sensor connects through a JST-XH harness rather than direct jumper wires,
so a pod can be opened, a sensor swapped, and nothing resoldered.

1. Cut the 10-wire ribbon into lengths, keeping the colour order consistent
   across every harness you make. Getting this wrong once and being consistent
   about it is better than getting it right sometimes.
2. Crimp a 2515 female pin onto each end and seat it in the matching housing.
   The connector sizes per harness are listed in the BOM tables.
3. Tug-test every crimp before it goes in the housing. A crimp that pulls out in
   your fingers will pull out under vibration, which is the one environment this
   whole project lives in.

Solder the pin headers onto the KX134 and INMP441 breakouts now, if the boards
did not ship with them fitted.

---

## 4. Build the base station

### 4.1 Wire it

Three peripherals hang off the real-time half of the board. Nothing hangs off
the Linux half.

| Peripheral | Signal | Pin |
|---|---|---|
| KX134 accelerometer | SPI SCK / MISO / MOSI | D13 / D12 / D11 |
| | Chip select | D8 |
| | INT1, buffer-full interrupt | D9 |
| INMP441 microphone | SAI1 clock / frame-sync / data | SCL / D10 / A4 |
| WS2812B ring | Data in | D3 |

Pins are the UNO Q's own header labels, which is what the board is silkscreened
with. The microphone's bit clock is the one signal without a D-number: it comes
out on the dedicated **SCL** pin. The I2C peripheral is disabled to free it, and
nothing in this project uses I2C.

The editable schematic is
[`hardware/kicad/base_station.kicad_sch`](../hardware/kicad/base_station.kicad_sch),
with a one-page PDF next to it. Both tables in this guide are transcribed from
the firmware itself, not from a drawing:
[`base-station/sketch/accel_sampler.cpp`](../base-station/sketch/accel_sampler.cpp),
[`mic_sampler.cpp`](../base-station/sketch/mic_sampler.cpp) and
[`rgb_display.cpp`](../base-station/sketch/rgb_display.cpp) for this board,
[`satellite/include/board_pins.h`](../satellite/include/board_pins.h) for the
satellite.

### 4.2 Assemble the pod

1. Seat the UNO Q in the back half of the shell.
2. Fit the Fresnel lens into the bezel's lens insert, over the LED matrix.
3. Pop the diffuser cap off the 9 W bulb and fit it over the WS2812B ring. That
   cap is the status dome, and it is the only reason the bulb is on the parts
   list.
4. Plug the three harnesses in and close the shell.
5. Press the ring magnet into the mount foot. The pocket is sized as an
   interference fit, so it goes in with thumb pressure and stays there. No
   fastener and no adhesive.

**Where you put the finished pod matters as much as which sensor you bought.**
Mount it rigidly, as close to the bearing as the geometry allows. A soft or loose
mount is a low-pass filter you did not ask for, and it removes exactly the
high-frequency content that early bearing faults live in.

### 4.3 Provision the board, once

These configure things outside the application container and only need running
once per board:

```sh
cd base-station
./provision-spi.sh      # the MCU-to-Linux SPI bulk link
./provision-baud.sh     # sets the serial link to 500000 baud on the Linux side
./provision-wifi.sh     # Wi-Fi onboarding: hotspot fallback + captive portal
```

`provision-baud.sh` matters more than it looks. The Linux-side router's baud must
match the firmware's, and a mismatch breaks the whole link silently, with no
error anywhere.

### 4.4 Flash the real-time side

Open [`base-station/sketch/`](../base-station/sketch/) in Arduino App Lab and
flash it to the STM32U585.

### 4.5 Build, deploy and run the Linux side

```sh
cd base-station
./start_dashboard.sh
```

This forces normal (non-raw-capture) mode, builds, flashes, pushes the
application, waits for its container, and prints **the board's own LAN IP URL**.

Use that link, not a localhost one. A real deployment has no port forwarding
available, and testing over one hides problems you will meet later.

Open it and the base station's own machine appears on its own. Nothing has been
trained yet, but the sensing half of the loop is already live and watchable:
vibration and audio spectra, time-domain traces, and a status ring that goes
solid the moment real data starts flowing.

### 4.6 Put it on the shop network

If there is Wi-Fi on the floor, join it from the dashboard's **Network** tab.

If there is none, the base station raises its own `EPM-BaseStation` hotspot and
runs a captive portal, so a phone that joins it lands straight on the same
"pick a network, type a password" flow. Satellites and the dashboard then connect
to the base station directly, and the whole system works with no network
infrastructure at all.

### 4.7 Telegram alerts, optional

One secret. Set `TELEGRAM_BOT_TOKEN` as the `arduino:telegram_bot` brick's
variable through App Lab's interface, then re-add that brick to `app.yaml`. The
bot's username is resolved automatically at startup, so there is no second value
to configure. With the token unset, every alert path no-ops cleanly.

---

## 5. Build a satellite node

### 5.1 Wire it

| Signal | Pin | Notes |
|---|---|---|
| KX134 SPI SCK / MISO / MOSI | D8 / D9 / D10 | The board's fixed hardware SPI pins |
| KX134 chip select | D6 | |
| KX134 INT1, buffer-full | D7 | |
| INMP441 BCLK / SCK | D1 | |
| INMP441 WS / LRCLK | D2 | |
| INMP441 SD, data in | D3 | |
| WS2812B ring data in | D5 | |

D0 and D4 are unused.

**The KX134 breakout's silkscreen lies to you here.** It is a dual-protocol
part, and the three SPI pins are screen-printed with their I2C-mode names:
`SCL` is SPI clock, `ADR` is data out (MISO), and `SDA` is data in (MOSI). Wire
by the electrical role above, not by the label you can read on the board.

The XIAO ESP32-S3 breaks out only 11 GPIOs, so every assignment above is chosen
to keep the fixed hardware SPI lines free for the accelerometer, the one
peripheral that genuinely needs them.

**There is no per-unit ID to set.** Node identity is derived from the board's own
Wi-Fi MAC address. No jumper to solder, no build flag to change between units.

Schematic:
[`hardware/kicad/satellite_node.kicad_sch`](../hardware/kicad/satellite_node.kicad_sch).

### 5.2 Assemble the pod

Same as [§4.2](#42-assemble-the-pod), minus the Fresnel lens. The satellite bezel
has no lens window.

### 5.3 Flash it

```sh
cd satellite
pio run                # build
pio run -t upload      # flash over USB
pio device monitor     # optional serial console, 115200 baud
```

**No credential is compiled in.** For a bench board being reflashed constantly, a
dev-only shortcut exists: pass `WIFI_SSID` and `WIFI_PASSWORD` as build flags in
`platformio.ini` and the node seeds its storage on first boot and skips the
portal. A real build passes neither, and the shortcut is a no-op.

If this is your first satellite and something does not come up, the stage-by-
stage bring-up guide is
[`SATELLITE_BRINGUP_GUIDE.md`](SATELLITE_BRINGUP_GUIDE.md).

### 5.4 Onboard it

1. **Power it up.** A node with no saved credentials raises **its own access
   point**, named from its own hardware address, for example `EPM-SAT-a4cf12`.
   Ten unconfigured nodes on a bench are ten distinguishable networks.
2. **Join it from any phone.** No app. The setup page opens by itself, through
   the same captive-portal mechanism airport Wi-Fi uses.
3. **Fill in three fields.** The shop's Wi-Fi name, its password, and the MQTT
   broker address, which comes pre-filled with `epm-base.local`. It is a field
   rather than a constant because mDNS is sometimes blocked on factory networks,
   and when it is, a technician needs to type an address rather than reflash a
   board.
4. **It tests before it commits.** Submitting does not blindly save. The node
   tries the credentials first and writes them to storage only on success, so a
   typo cannot strand a device on a machine you now need a ladder to reach.
5. **It appears.** No pairing step, no ID to type in. The asset shows up on the
   Fleet page the moment its first frame lands, ready to be set up.

---

## 6. Commission your first machine

A node that is wired and online is not yet monitoring anything. Every asset is
taught its own normal once, from the dashboard, in four to six minutes.

Find the asset in the list and press **Set up**. Six steps:

| # | Step | Machine | Required | What it produces |
|---|---|---|---|---|
| 1 | Name and class | either | yes | The name alerts print, and the class recordings group by |
| 2 | Off | **switched off** | yes | This sensor's own noise floor, per frequency bin |
| 3 | Running conditions | **running** | yes, at least one | The training batch, the running reference, and labelled healthy recordings |
| 4 | Train | either | yes | This asset's own model, its normalisation statistics and its two thresholds |
| 5 | Trip output | running, then stopped by the system | no | Which motor stops this machine, confirmed rather than guessed |
| 6 | Done | either | — | A summary. The asset goes live |

**Step 2 is the one instruction no computer can check.** Nothing in the software
can confirm the machine is actually switched off. A baseline captured while the
machine runs teaches the system that its own vibration is silence, and the
running/stopped gate will never work correctly until you re-measure it.

**Step 5 needs the motor rig, or a real machine wired to a trip output.** Skip it
if you have neither. The outputs that have announced themselves appear as real
candidates; press **Test** and watch the machine actually stop. One motor may
only be claimed by one asset.

Setup state lives in memory only. Restart the dashboard mid-setup and the current
step restarts, because a batch resumed across a restart is worse data than a
fresh one.

That is the whole of fault *detection*. Naming the fault type needs a second
model, in [§6.1](#61-optional-naming-the-fault-type).

### 6.1 Optional: naming the fault type

Detection tells you a machine has drifted from healthy. The classifier names
*what kind* of fault it is, and it is trained per asset class rather than per
machine, so one model covers every pump in the shop.

Five steps, and only one happens outside the dashboard.

- **Record.** On the machine's row, open the **Record** drawer, type a label
  such as `bearing_wear`, and capture the machine while that fault is present.
- **Link.** On the **Classifier** tab, each asset class has a card. Press **Link
  to Edge Impulse** and sign in. A project is created for that class over the
  API; you never visit Studio to do it.
- **Upload.** Push the labelled recordings to that project from the same card.
  This is the only step in the entire system that needs an internet connection.
- **Train.** This one step is deliberately left in Edge Impulse Studio. Tuning
  DSP parameters and reading a confusion matrix is what Studio is for, and a
  button in this dashboard would only have frozen one architecture forever. The
  card links straight to the project.
- **Fetch.** Press **Fetch trained model**. It runs the build, downloads the
  deployment archive, extracts the `.tflite` and saves it under the class name.
  It is a background job with progress streamed to the browser, because an Edge
  Impulse build takes real minutes.

From the moment that file lands, **every asset of that class is being
classified**, with no restart and no per-node action.

---

## 7. Optional: the motor test rig

Only needed to reproduce the project's measurements or to see the trip fire
end to end.

**1. Set each driver's current limit before applying power.** Each A4988 or
DRV8825 has a small potentiometer setting its reference voltage. Under-current
skips steps, over-current cooks the driver.

- A4988: `Vref ≈ Imax × 8 × Rsense`
- DRV8825: `Vref ≈ Imax / 2`

**2. Wire it.**

| Signal | Pin | Notes |
|---|---|---|
| Shared driver enable (`~ENABLE`) | D8, active-LOW | **One line for all three driver sockets.** The shield has no per-motor hardware enable |
| Motor 1 (X) STEP / DIR | D2 / D5 | |
| Motor 2 (Y) STEP / DIR | D3 / D6 | |
| Motor 3 (Z) STEP / DIR | D4 / D7 | |

The shared enable line is why the trip is implemented as a per-motor step-pulse
halt rather than a hardware disable. Pulling `~ENABLE` high de-energises all
three drivers, which would stop two healthy machines to protect one faulty one.

**3. Flash** [`motor-driver/src/main.cpp`](../motor-driver/src/main.cpp) to the
Arduino Uno with PlatformIO.

**4. Start the rig host,** which serves the control page and receives trips:

```sh
cd motor-driver
./start_motor_driver.sh                                # broker on localhost
./start_motor_driver.sh --mqtt-host <base-station-ip>  # or over the LAN
```

The Uno's port is autodetected; pass `--port` if two boards are attached. Open
**http://localhost:8000/** in Chrome or Edge, click **Connect**, and pick the
Uno's port. The rig starts with **one** motor installed; the empty slots add the
others, and each one added is announced to the base station as a trip output
straight away. Add `--profile` to run a scripted capture profile instead of
driving by hand.

**5. Claim it** at step 5 of that asset's setup ([§6](#6-commission-your-first-machine)).
Back on the control page, the motor now carries a **PROTECTED** badge naming the
asset. If the trip ever fires, its card turns red and locks until a human presses
**Reset & re-arm**.

The printed rig parts are in [`3d-models/`](../3d-models/). Pick belt-drive
(`c1`, `c2`, `c3`) or direct-drive (`c6`, `c7`), then add the shared flywheel
(`c4`, `c5`) either way. Moving or removing M6 bolts around the flywheel's bolt
circle is the fault-injection mechanism.

---

## 8. Building with no hardware

### 8.1 No hardware at all

This runs the **real** dashboard application on your own machine, fed by a
simulator that speaks the **real** wire protocol, replaying **real** captured
sensor data. It is not a mock: the registry, the feature pipeline, the
autoencoder, the setup flow, the thresholds, the classifier and the whole
frontend are the same code that runs on the board.

You need an MQTT broker on `localhost:1883`. The script checks for one and will
not start one for you:

```sh
sudo apt-get install -y mosquitto mosquitto-clients
sudo systemctl enable --now mosquitto
```

Then:

```sh
cd base-station
./start_desktop_dashboard.sh
```

That creates a virtual environment, installs dependencies, starts the application
on **port 8180** with an isolated data directory so it can never touch a real
device's registry or history, starts one simulated node, pre-configures it, and
prints both URLs.

The simulated node starts **offline** on purpose. Open its own control page and
press *Go Online*, or skip that with `--auto-online`.

| Flag | Effect |
|---|---|
| `--nodes N` | Run N independent simulated nodes, each with its own control page |
| `--captures-dir DIR` | Replay a different folder of `.npz` captures. Defaults to `base-station/captures/` |
| `--captures-dir ""` | Fall back to generated synthetic captures instead of real recordings |
| `--auto-online` | Bring the node online without a click |
| `--host 0.0.0.0` | Bind on every interface, so you can open the dashboard from a phone to check the mobile layout |

Each simulated node's page lets you pick which capture file it streams, toggle
the accelerometer and microphone independently, adjust FFT bin counts live, and
watch its status LED change as the base station pushes status to it, exactly as a
real node would.

**What you will not see:** the `base_station` asset itself. Its data comes from
the SPI-connected sampling chip, which does not exist on a laptop. Only
MQTT-driven nodes appear. That is expected, not a failure.

### 8.2 A simulated node against a real base station

Once you have a UNO Q running ([§4](#4-build-the-base-station)), point the same
simulator at the real device over your LAN. This is how most of the fleet-level
behaviour in this project was exercised without building ten satellites.

One-time, on the device. This needs a password typed on-device, so no script can
do it for you:

```sh
adb shell
sudo apt-get update && sudo apt-get install -y mosquitto mosquitto-clients
echo -e 'listener 1883 0.0.0.0\nallow_anonymous true' | sudo tee /etc/mosquitto/conf.d/lan.conf
sudo systemctl enable --now mosquitto
```

The broker lives **on the UNO Q**, not on your laptop, matching how a real
satellite has to work since it is a sensor with nowhere else to publish. Then,
from your machine:

```sh
cd base-station
./start_sim_node.sh --captures-dir captures --nodes 2
```

The simulator connects out over plain LAN, exactly as a real node would. USB is
used only for occasional setup steps, never for live traffic, so a momentary USB
blip cannot flip a node offline on the dashboard.

---

## 9. Changing the wire format

[`base-station/telemetry_schema.json`](../base-station/telemetry_schema.json) is
the single source of truth for the frame format. Any edit must be followed by
regenerating every generated side, so the base station, the ingestion parser and
the satellite firmware cannot drift apart:

```sh
python3 base-station/python/tools/gen_telemetry_schema.py
```

---

## Where to go next

- [`BILL_OF_MATERIALS.md`](BILL_OF_MATERIALS.md) — what to buy
- [`3d-models/README.md`](../3d-models/README.md) — what each printable file
  contains, and which ones you need
- [`SATELLITE_BRINGUP_GUIDE.md`](SATELLITE_BRINGUP_GUIDE.md) — stage-by-stage
  satellite debugging when a module does not come up
- [`Dashboard_LAN_Access_Guide.md`](Dashboard_LAN_Access_Guide.md) — reaching the
  dashboard from other machines

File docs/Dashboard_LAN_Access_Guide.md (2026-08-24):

# Dashboard LAN Access Guide

How to view the dashboard (`base-station/python/frontend/`, served by
`base-station/python/main.py`) from the host machine's browser and from a
phone on the same Wi-Fi, when `main.py` is run inside WSL2.

## Run the server

```
python3 base-station/python/main.py --mqtt-host localhost
```

Binds to `0.0.0.0:8080` by default (REST + WebSocket + static frontend,
one port).

## View on the host machine (Windows, from WSL2)

Windows' localhost forwarding proxies `127.0.0.1` into the WSL2 VM
automatically, so just open:

```
http://localhost:8080
```

## View on a phone (same Wi-Fi)

WSL2's localhost forwarding does **not** cover traffic arriving on a
LAN-facing Windows interface (e.g. Ethernet/Wi-Fi), so one manual
port-forward from Windows to the WSL2 VM is required.

1. Get the WSL2 VM's current IP (changes on reboot):
   ```
   wsl hostname -I
   ```
2. In an **Administrator PowerShell** on Windows, forward the port
   (replace the IP with the output of step 1):
   ```powershell
   netsh interface portproxy add v4tov4 listenport=8080 listenaddress=0.0.0.0 connectport=8080 connectaddress=<WSL_IP>
   ```
3. Allow it through Windows Firewall (one-time):
   ```powershell
   New-NetFirewallRule -DisplayName "MPU Dashboard 8080" -Direction Inbound -LocalPort 8080 -Protocol TCP -Action Allow
   ```
4. Find the host machine's LAN IPv4 address (the adapter actually
   connected to the router, e.g. `Ethernet` or `Wi-Fi`):
   ```powershell
   ipconfig
   ```
5. On the phone, browse to:
   ```
   http://<host-LAN-IP>:8080
   ```

## Notes

- The WSL2 VM IP can change across reboots. If the phone can no longer
  connect, re-run step 2 above with the new IP from `wsl hostname -I`.
- To remove the port-forward rule later:
  ```powershell
  netsh interface portproxy delete v4tov4 listenport=8080 listenaddress=0.0.0.0
  ```

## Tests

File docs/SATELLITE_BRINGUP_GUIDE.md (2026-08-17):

# Satellite Node Bring-Up Guide (XIAO ESP32-S3 → Desktop Dashboard)

A step-by-step guide for bringing up a **satellite node** on a Seeed Studio
XIAO ESP32-S3, talking to the dashboard running **on your desktop** — no UNO Q
in the picture. Written for someone who has never seen this repo before.

You'll bring the board up **one module at a time**: heartbeat LED → WiFi/MQTT
link → status ring → microphone → accelerometer → both together. Each stage
tells you exactly what to flash, what to watch in the serial log, and what to
check on the dashboard.

---

## 0. The 30-second picture

Normally a satellite node talks to the **UNO Q** base station over WiFi/MQTT.
For bring-up we cut the UNO Q out entirely and let your **desktop play the base
station's role**: the desktop runs the MQTT broker *and* the dashboard. The
ESP32 just needs to join the same network and publish to that broker.

```
  ┌───────────────────┐        WiFi / MQTT         ┌──────────────────────────┐
  │  XIAO ESP32-S3     │  ─────────────────────────▶│  Your desktop            │
  │  (satellite node)  │   epm/<node_id>/data       │                          │
  │                    │                            │  • Mosquitto broker :1883│
  │  KX134 accel (SPI) │◀───────────────────────────│  • Dashboard  :8180      │
  │  INMP441 mic (I2S) │   epm/<node_id>/cmd         │    (base-station/python) │
  │  WS2812 ring       │   (STATUS_LED)             │                          │
  └───────────────────┘                            └──────────────────────────┘
```

- **`epm/<node_id>/data`** — node → desktop. The binary telemetry frame
  (mic + accel FFT spectra). This is what makes the node appear on the dashboard.
- **`epm/<node_id>/cmd`** — desktop → node. `STATUS_LED` commands that drive the
  WS2812 ring color.
- **`node_id`** — the last 6 hex digits of the board's WiFi MAC, lowercase
  (e.g. `a1b2c3`). Automatic — no per-board config. You'll read it off the
  serial log.

---

## 1. What you need

**Hardware**

- Seeed Studio XIAO ESP32-S3
- KX134-1211 accelerometer breakout
- INMP441 I2S MEMS microphone
- WS2812B 8-pixel ring (same ring the base station uses)
- USB-C cable (data, not charge-only)
- Jumper wires

**Software**

- A desktop on the **same WiFi/LAN** as the board will join (Linux assumed
  below; the repo's own tooling targets Linux).
- [PlatformIO](https://platformio.org/) — either the VS Code extension or the
  `pio` CLI. Install the CLI with: `pip install -U platformio`
- `mosquitto` + `mosquitto-clients` (the MQTT broker + test tools)

---

## 2. Wiring (do this once)

Pin map for the XIAO ESP32-S3. Full rationale is in
[satellite/include/board_pins.h](../satellite/include/board_pins.h).

| Peripheral | Signal | XIAO pin | Notes |
|---|---|---|---|
| **KX134 accel** | SCL  | **D8** | hardware SPI SCK (fixed); board silkscreen label, chip runs in SPI mode |
| | ADR  | **D9** | hardware SPI MISO (fixed); board silkscreen label |
| | SDA  | **D10** | hardware SPI MOSI (fixed); board silkscreen label |
| | CS | **D6** | software chip-select |
| | INT1 | **D7** | buffer-full interrupt |
| **INMP441 mic** | SCK (BCLK) | **D1** | |
| | WS (LRCLK) | **D2** | |
| | SD (data) | **D3** | |
| | **L/R** | **GND** | **must tie to GND** → left channel (firmware reads left only) |
| **WS2812 ring** | DIN | **D5** | 8 pixels |

> ⚠️ **Power is 3.3 V, not 5 V.** Feed all three peripherals from the XIAO's
> **3V3** pin and share **GND**. The WS2812 ring runs fine off 3V3 at 8 pixels.

> ℹ️ The **onboard user LED** (the little LED on the XIAO itself, GPIO21) is a
> separate "heartbeat" — nothing to wire. It's your first sign of life.

---

## 3. Codebase tour (what you're flashing)

Everything for the node lives under [satellite/](../satellite/). It's an
Arduino/PlatformIO project. Full detail in
[satellite/README.md](../satellite/README.md).

**WiFi/MQTT credentials are no longer compiled in.** As of
[docs/WIFI_ONBOARDING_PLAN.md](WIFI_ONBOARDING_PLAN.md) §2 the node stores them at
runtime in NVS flash, set either by joining the node's own captive portal (the
normal path — see §5a below) or via a **dev-bench shortcut** in
[satellite/include/app_config.h](../satellite/include/app_config.h) that this guide
still uses, since it's the fastest path for bring-up:

| Setting | What it does |
|---|---|
| `WIFI_SSID` / `WIFI_PASSWORD` | dev-bench shortcut: if both are set to real values (not the `"CHANGE_ME"` placeholder), the node auto-seeds NVS with them on its **first** boot only and skips the portal entirely |
| `MQTT_BROKER_HOST` / `MQTT_BROKER_PORT` | same shortcut, plus doubles as the portal form's broker-field prefill (default `epm-base.local` — irrelevant for desktop bring-up, always override to your desktop's IP, §4b) |
| `MIC_SENSOR_ENABLED` (0/1) | turn the mic task on/off |
| `ACCEL_SENSOR_ENABLED` (0/1) | turn the accel task on/off |

The two `*_ENABLED` flags are how we bring sensors up one at a time.

> 🔑 **NVS persists across `pio run -t upload`.** A plain reflash does not touch
> saved credentials — the seed-from-`app_config.h` step only fires on a genuinely
> first boot (nothing in NVS yet). So once a board has joined your desktop once
> (either path), later stages in this guide that just flash new sensor config
> **won't** re-prompt for WiFi or re-run the portal. If you need a clean slate
> (e.g. testing the portal itself, or switching a board to a different desktop),
> erase flash first: `pio run -t erase` (wipes everything, including the app —
> reflash after).

**The firmware = 5 FreeRTOS tasks**, started in this order by
[satellite/src/main.cpp](../satellite/src/main.cpp):

1. **transport** — owns WiFi + MQTT, including the provision/connect/recover state
   machine (join saved creds → connect; no/failed creds → own AP + captive portal;
   dropped WiFi → silent retry, then AP again). Publishes telemetry, receives LED
   commands.
   → [transport_task.cpp](../satellite/src/threads/transport_task.cpp),
   [hal_provisioning.h](../satellite/include/hal/hal_provisioning.h),
   [hal_credentials.h](../satellite/include/hal/hal_credentials.h)
2. **rgb_display** — drives the WS2812 ring from `STATUS_LED` commands.
   → [rgb_display_task.cpp](../satellite/src/threads/rgb_display_task.cpp) / [rgb_ws2812.cpp](../satellite/src/drivers/rgb_ws2812.cpp)
3. **mic_sampler** — reads the INMP441 over I2S, runs an FFT.
   → [mic_sampler_task.cpp](../satellite/src/threads/mic_sampler_task.cpp) / [mic_i2s.cpp](../satellite/src/drivers/mic_i2s.cpp)
4. **accel_sampler** — reads the KX134 over SPI, FFTs each axis, sums them.
   → [accel_sampler_task.cpp](../satellite/src/threads/accel_sampler_task.cpp) / [kx134.cpp](../satellite/src/drivers/kx134.cpp)
5. **fuser** — every 200 ms, grabs the latest mic + accel spectra and publishes
   one telemetry frame over MQTT.
   → [fuser_task.cpp](../satellite/src/threads/fuser_task.cpp)

Plus the **heartbeat**: `loop()` in `main.cpp` blinks the onboard LED every
500 ms once all five tasks start successfully.

> 🔑 **Two rules that will save you an hour:**
>
> 1. **A sensor whose flag is ON but is broken/unwired will halt the entire
>    boot.** If `hal_accel_init()` can't find the KX134 (bad wiring), the node
>    prints `accel_sampler_task_start failed` and stops — **no heartbeat, no
>    publishing at all**. So enable a sensor *only* once it's wired. That's the
>    whole reason we bring them up one at a time.
> 2. **A node locks in its sensor set on its very first telemetry frame.** If
>    the node's first frame carried only mic, the dashboard commits it to
>    "mic-only" and will then *reject* any later frame that also has accel. So
>    when you change which sensors are enabled, you must **reset the node in the
>    dashboard's registry** (Section 6, Stage 5 shows how).

---

## 4. Desktop setup (the "base station" side)

Do this once on the desktop. Everything here runs from the repo root.

### 4a. Install and configure the MQTT broker

```sh
sudo apt-get install -y mosquitto mosquitto-clients
```

By default Mosquitto only listens on `localhost`, which the ESP32 can't reach.
Open it to the LAN with a small config file:

```sh
sudo tee /etc/mosquitto/conf.d/epm.conf >/dev/null <<'EOF'
listener 1883 0.0.0.0
allow_anonymous true
EOF
sudo systemctl restart mosquitto
```

> ⚠️ This makes the broker reachable by anything on your network. Fine for a lab
> LAN; don't do it on an untrusted network.

If you run a firewall, allow the port: `sudo ufw allow 1883/tcp`

### 4b. Find the desktop's IP (the board needs it)

```sh
hostname -I | awk '{print $1}'
```

Write this down — it goes into `MQTT_BROKER_HOST` in Section 5. Example:
`192.168.1.50`.

### 4c. Start the dashboard

```sh
cd base-station
./start_desktop_dashboard.sh
```

This sets up a Python venv, checks the broker is up, and launches the dashboard
at **http://localhost:8180**. It also starts **one simulated node** — that's on
purpose: it's a known-good reference so you can confirm the dashboard works
*before* your real board is talking. Leave it running; Ctrl+C stops everything.

> The `base_station` node will never appear (that's the UNO Q's own sensors,
> which aren't here). Only MQTT satellite nodes show up. Expected.

**✅ Checkpoint:** Open http://localhost:8180 — you should see the simulated
satellite node. In another terminal, watch the raw MQTT traffic:

```sh
mosquitto_sub -h localhost -t 'epm/#' -v
```

You'll see frames flowing from the sim node's topic. This is your ground truth
for the rest of the guide — when your real board publishes, it shows up here too.

---

## 5. Firmware setup (dev machine)

### 5a. Point the board at your desktop

Two ways to get credentials onto the board. Either works; pick one.

**Option A — dev-bench shortcut (what this guide uses).** Edit
[satellite/include/app_config.h](../satellite/include/app_config.h):

```c
#define WIFI_SSID         "YourWiFiName"
#define WIFI_PASSWORD     "YourWiFiPassword"
#define MQTT_BROKER_HOST  "192.168.1.50"   // the desktop IP from Section 4b
```

The defaults are all `"CHANGE_ME"` / `"epm-base.local"` — replace them with real
values and the node will auto-seed NVS with these on its first boot after flashing
(see the NVS note in Section 3) and skip the portal entirely.

> 🔒 Don't commit your WiFi password. If you'd rather not touch the file, you can
> pass these as build flags in `platformio.ini` instead (see the README) — the
> effect is identical either way, since both just become the compiled `#define`.

**Option B — the real captive portal** (what a deployed node actually uses, no
`app_config.h` edit at all): leave `app_config.h` untouched, flash, and once booted
the node has no saved creds so it starts its own AP instead. Join it from your
phone/laptop:

1. The node's serial log prints its AP SSID: `EPM-SAT-<node_id>` (node_id is its
   MAC-derived id, same one Stage 2 below teaches you to read). This AP is open —
   no password needed to join it.
2. Join that WiFi network. A login-style page should **auto-open** (same "airport
   WiFi" captive-portal experience as the base station, dark-themed to match the
   dashboard) — if it doesn't, browse to `http://192.168.4.1`. Tap your desktop's
   network from the scanned list to fill in its SSID, or type it manually if it
   doesn't show up.
3. Fill in your desktop's WiFi password (leave blank if it's open), and put your
   desktop's IP from Section 4b into the **IP address** field — the prefilled
   "Base station address (mDNS name)" field (`epm-base.local`) only resolves on the
   real UNO Q's network, not your desktop, and a filled-in IP always wins over it.
4. Submit. The page tests the join without disconnecting you — on success it says
   so and the node's own AP switches off a few seconds later; on failure (e.g. typo
   in the password) it shows an error inline and you can retry immediately, still
   connected.

Use Option B specifically if you want to exercise the onboarding feature itself,
or once boards start production builds that don't compile in real credentials.

**Already connected to the wrong network, or the right network with a typo'd
broker address, and the node's own AP is gone?** Hold the XIAO's onboard **BOOT**
button (the same one used to enter bootloader mode) for **3 seconds** — this
forces the AP+portal back up from any state, including a fully working
connection, without erasing anything or losing the existing WiFi link until you
actually submit a new form. See
[WIFI_ONBOARDING_PLAN.md](WIFI_ONBOARDING_PLAN.md)'s 2026-08-17 follow-up for why
this exists and how it's implemented.

### 5b. USB / flashing basics

From the [satellite/](../satellite/) folder:

```sh
cd satellite
pio run                 # build
pio run -t upload       # flash over USB-C
pio device monitor      # serial log @ 115200 baud
```

- **Serial permission error (Linux):** add yourself to the `dialout` group once:
  `sudo usermod -aG dialout $USER`, then log out/in.
- **Upload can't find / open the port:** put the board in bootloader mode — hold
  **BOOT**, tap **RESET**, release **BOOT**, then re-run upload.
- The XIAO uses native USB — the **same port** does both flashing and the serial
  log.

---

## 6. Bring-up, one module at a time

Keep two terminals open on the desktop the whole time:
- `pio device monitor` (from `satellite/`) — the board's serial log
- `mosquitto_sub -h localhost -t 'epm/#' -v` — raw MQTT traffic

---

### Stage 1 — Heartbeat LED (is the board alive?)

**Goal:** prove the flash worked and the board boots.

**Config** — sensors OFF so nothing can block the boot:

```c
#define MIC_SENSOR_ENABLED   0
#define ACCEL_SENSOR_ENABLED 0
```

Flash it: `pio run -t upload && pio device monitor`

**✅ You should see** in the serial log:

```
edgeai-predictive-monitor satellite node booting...
...
edgeai-predictive-monitor satellite node booted
```

…and the **onboard LED blinking ~once per second**.

- **No heartbeat / no "booted" line?** Read the last log line — it names which
  `*_task_start failed`. With both sensors off, only `transport` or `rgb` could
  fail (rare). Re-check the flash succeeded.

---

### Stage 2 — WiFi + MQTT link (does it reach the desktop?)

**Goal:** the board joins WiFi and connects to the broker. (Still sensors-off.)

Nothing to change — same build. Just watch the serial log after boot.

**If you used Option A (app_config.h shortcut), you should see:**

```
[transport] seeded NVS from compiled-in WIFI_SSID/WIFI_PASSWORD (dev-bench escape hatch)
[transport] attempting WiFi join to "YourWiFiName"...
[transport] WiFi joined, IP=192.168.1.xx
[transport] connecting to MQTT broker 192.168.1.50:1883 as "a1b2c3"...
[transport] MQTT connected, subscribed to epm/a1b2c3/cmd
```

The first "seeded NVS" line only prints on a genuinely first boot (Section 3's NVS
note) — a later reflash of the same build goes straight to "attempting WiFi join".

**If you used Option B (captive portal),** the log instead shows the node's own AP
coming up (no "attempting WiFi join" until you actually submit the form):

```
[transport] WiFi join timed out    <- only if this followed a failed saved-creds attempt; skip on a true first boot
```

then, after you submit the portal form from your phone:

```
[transport] attempting WiFi join to "YourWiFiName"...
[transport] WiFi joined, IP=192.168.1.xx
[transport] connecting to MQTT broker 192.168.1.50:1883 as "a1b2c3"...
[transport] MQTT connected, subscribed to epm/a1b2c3/cmd
```

**That `a1b2c3` is your node_id — note it down.** It's also in the AP SSID
(`EPM-SAT-a1b2c3`) if you used Option B.

**Ring color while this is happening** (Option B, or any later re-provision; full
rationale in [WIFI_ONBOARDING_PLAN.md](WIFI_ONBOARDING_PLAN.md)'s "RGB status
colors" note and its 2026-08-17 follow-up): magenta slow breathe = AP up, waiting
for a submission; magenta fast breathe = testing a submitted join; amber breathe =
last attempt failed, portal still up, retry; solid cyan = WiFi **and** MQTT both
connected; **red breathe = WiFi joined fine but the MQTT broker itself is
unreachable** (this is the one to watch for the "no MQTT connected" row below).

Troubleshooting:

| Symptom | Cause / fix |
|---|---|
| `WiFi join timed out`, ring goes to amber breathe | Wrong SSID/password, or board not on 2.4 GHz (ESP32-S3 is 2.4 GHz only). Bounded to 15s now, not indefinite — if using Option A, fix `app_config.h` and reflash; NVS won't have saved a failed attempt, so it'll seed again from the corrected values. If using Option B, just resubmit the portal form with the fix — the AP is still up. |
| WiFi joins, but no "MQTT connected" (ring stays on red breathe) | Wrong desktop IP in the portal's IP field/`MQTT_BROKER_HOST`, broker not listening on `0.0.0.0`, or firewall. Recheck Section 4a. From the desktop try `mosquitto_sub -h <desktop-ip> -t test` to prove the broker is reachable by IP, not just localhost. |
| `MQTT connect failed, rc=...` | Broker reachable but rejecting. Confirm `allow_anonymous true`. |
| Ring stuck on magenta slow breathe forever | Node has no saved creds and nobody's submitted the portal form yet — expected if you're using Option B and haven't joined `EPM-SAT-<id>` yet. |
| Portal page doesn't auto-open on your phone | Auto-open behavior depends on the OS's captive-portal probe; browse to `http://192.168.4.1` manually as a fallback. |

> The node won't appear on the dashboard yet — with both sensors off it only
> sends empty "heartbeat" frames (no spectrum data), which the dashboard skips.
> That's expected. The next stages give it real data.

---

### Stage 3 — Status ring (the round trip)

**Goal:** confirm the WS2812 ring works. The ring is **driven by the dashboard**,
so we test it with a manual command for now.

The ring starts **blank** at boot (normal). Send it a color by hand from the
desktop — solid **red**, full brightness — replacing `a1b2c3` with your node_id:

```sh
printf '\x08\x00\x00\xff\x00\x00\x00\x00' \
  | mosquitto_pub -h localhost -t 'epm/a1b2c3/cmd' -s
```

**✅ You should see** the ring turn solid red, and in the serial log:

```
[transport] RX STATUS_LED rgb=0xff0000 mode=0 period_ms=0
```

Try green: `\x08\x00\xff\x00\x00\x00\x00\x00`. Try off: all-zero rgb.

> This proves the full command round trip: desktop → broker → node → ring. Once
> sensors are on, the dashboard sends these automatically based on node health
> (e.g. green = healthy). You won't need `mosquitto_pub` after this stage.

- **Ring stays dark / wrong colors?** Check DIN on **D5**, 3V3 power, shared GND.
  If serial shows the `RX STATUS_LED` line but the ring is dark, it's wiring/power,
  not firmware.

---

### Stage 4 — Microphone

**Goal:** first real telemetry — mic spectrum on the dashboard.

**Config:**

```c
#define MIC_SENSOR_ENABLED   1
#define ACCEL_SENSOR_ENABLED 0
```

Flash it. **✅ You should see** in the serial log after boot:

```
[accel_sampler] accel sensor disabled (ACCEL_SENSOR_ENABLED == 0)
[fuser] mic fs=48000 fft_size=1024 bin_count=512 | accel fs=0 fft_size=0 bin_count=0
```

…the heartbeat still blinking, and in `mosquitto_sub` a steady stream of frames
on `epm/<node_id>/data`.

**On the dashboard (http://localhost:8180):** your node appears (by its node_id),
with a **live mic spectrum / waterfall**. Make noise near the mic — tap it,
whistle — and the spectrum should react.

Troubleshooting:

| Symptom | Cause / fix |
|---|---|
| Boot halts, last line `mic_sampler_task_start failed` / `[mic_i2s] ... failed` | I2S init failed. Recheck SCK(BCLK)=D1, WS=D2, SD=D3, and 3V3/GND. |
| Node appears but spectrum is flat/dead | Mic wired but silent — confirm **L/R tied to GND**. Without it the left slot is never clocked. |
| Node never appears on dashboard | No data frames — recheck Stage 2 (MQTT). Confirm frames in `mosquitto_sub`. |

---

### Stage 5 — Accelerometer (+ the registry reset)

**Goal:** add the accelerometer so the node reports **both** channels.

> 🔑 **You must reset the node first.** In Stage 4 the node committed to
> "mic-only" on its first frame. If you just add accel, the dashboard will reject
> the new mic+accel frames (bin-count mismatch) and the node will look frozen.
> Clear it:
>
> ```sh
> # in the dashboard terminal: Ctrl+C to stop it, then:
> rm -rf base-station/.cache/data-desktop
> cd base-station && ./start_desktop_dashboard.sh
> ```
>
> This wipes the remembered node set (and the sim node's history) so your board
> can re-register with its new sensor set. Do this **every time** you change
> which sensors are enabled.

**Config** — both on:

```c
#define MIC_SENSOR_ENABLED   1
#define ACCEL_SENSOR_ENABLED 1
```

Flash it. **✅ You should see:**

```
[fuser] mic fs=48000 fft_size=1024 bin_count=512 | accel fs=12800 fft_size=1024 bin_count=512
```

Heartbeat blinking, frames flowing. On the dashboard the node now shows **both a
mic and an accel spectrum**. Tap the accelerometer / the surface it's on — the
accel spectrum should react.

Troubleshooting:

| Symptom | Cause / fix |
|---|---|
| Boot halts, `[kx134] WHO_AM_I mismatch: got 0xNN, expected 0x46` | The board can't talk to the KX134 over SPI. Check CS=D6, INT1=D7, and SCL/ADR/SDA=D8/D9/D10, plus 3V3/GND. A wrong `got` value = wiring; `got 0x00`/`0xff` usually = no connection at all. |
| `[kx134] no accel frame after 1000ms` repeating | SPI reads OK but no data-ready interrupt — check **INT1 → D7**. |
| Node stuck / dashboard not updating after adding accel | You skipped the registry reset above. |

---

### Stage 6 — Everything together

With both sensors live, the node runs the full pipeline. Leave it publishing and
watch the dashboard:

- The node's **status ring** now updates on its own (the dashboard pushes
  `STATUS_LED` based on health — no more `mosquitto_pub`).
- After ~50 frames (~10 s) the node gets **commissioned** and starts producing
  **anomaly scores** — the dashboard's health/anomaly view comes alive.

🎉 That's a fully working satellite node talking to your desktop.

---

## 7. Troubleshooting quick reference

| What you see | Where | Likely cause |
|---|---|---|
| No onboard heartbeat LED | board | boot halted — read the last serial line for which `*_start failed` |
| `WiFi join timed out`, ring goes to amber breathe | serial / ring | wrong WiFi creds / not 2.4 GHz — fix and reflash (Option A) or resubmit the portal form (Option B) |
| Ring stuck magenta slow breathe | ring | no saved creds yet and nobody's joined `EPM-SAT-<id>` + submitted the form (Option B, before submission) |
| WiFi OK, no MQTT, ring red breathe | serial / ring | wrong desktop IP (portal's IP field / `MQTT_BROKER_HOST`), broker not on `0.0.0.0`, firewall |
| Node absent from dashboard | dashboard | no *data* frames — check `mosquitto_sub`, check a sensor is enabled |
| `WHO_AM_I mismatch` | serial | KX134 SPI wiring (CS/INT1/SCK/MISO/MOSI) |
| `[mic_i2s] ... failed` | serial | INMP441 I2S wiring (WS/BCLK/SD) |
| Flat mic spectrum | dashboard | INMP441 L/R not tied to GND |
| Node freezes after enabling a new sensor | dashboard | forgot the registry reset (Stage 5) |
| Reflash didn't pick up new `app_config.h` WiFi/broker values | serial | NVS already has creds from an earlier boot — the seed step only fires once (Section 3). `pio run -t erase` for a clean slate. |

---
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

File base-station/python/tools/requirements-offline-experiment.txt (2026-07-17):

# Deps for tools/offline_experiment.py, beyond what ../requirements.txt
# (the on-device app's requirements, torch/psutil/statemachine) already
# covers -- matplotlib is only used by this local, laptop-side tool's
# --plot-out output and is never deployed to the device.
#
#   .venv/bin/pip install -r requirements.txt -r tools/requirements-offline-experiment.txt
#   .venv/bin/python tools/offline_experiment.py --sweep
matplotlib==3.11.0

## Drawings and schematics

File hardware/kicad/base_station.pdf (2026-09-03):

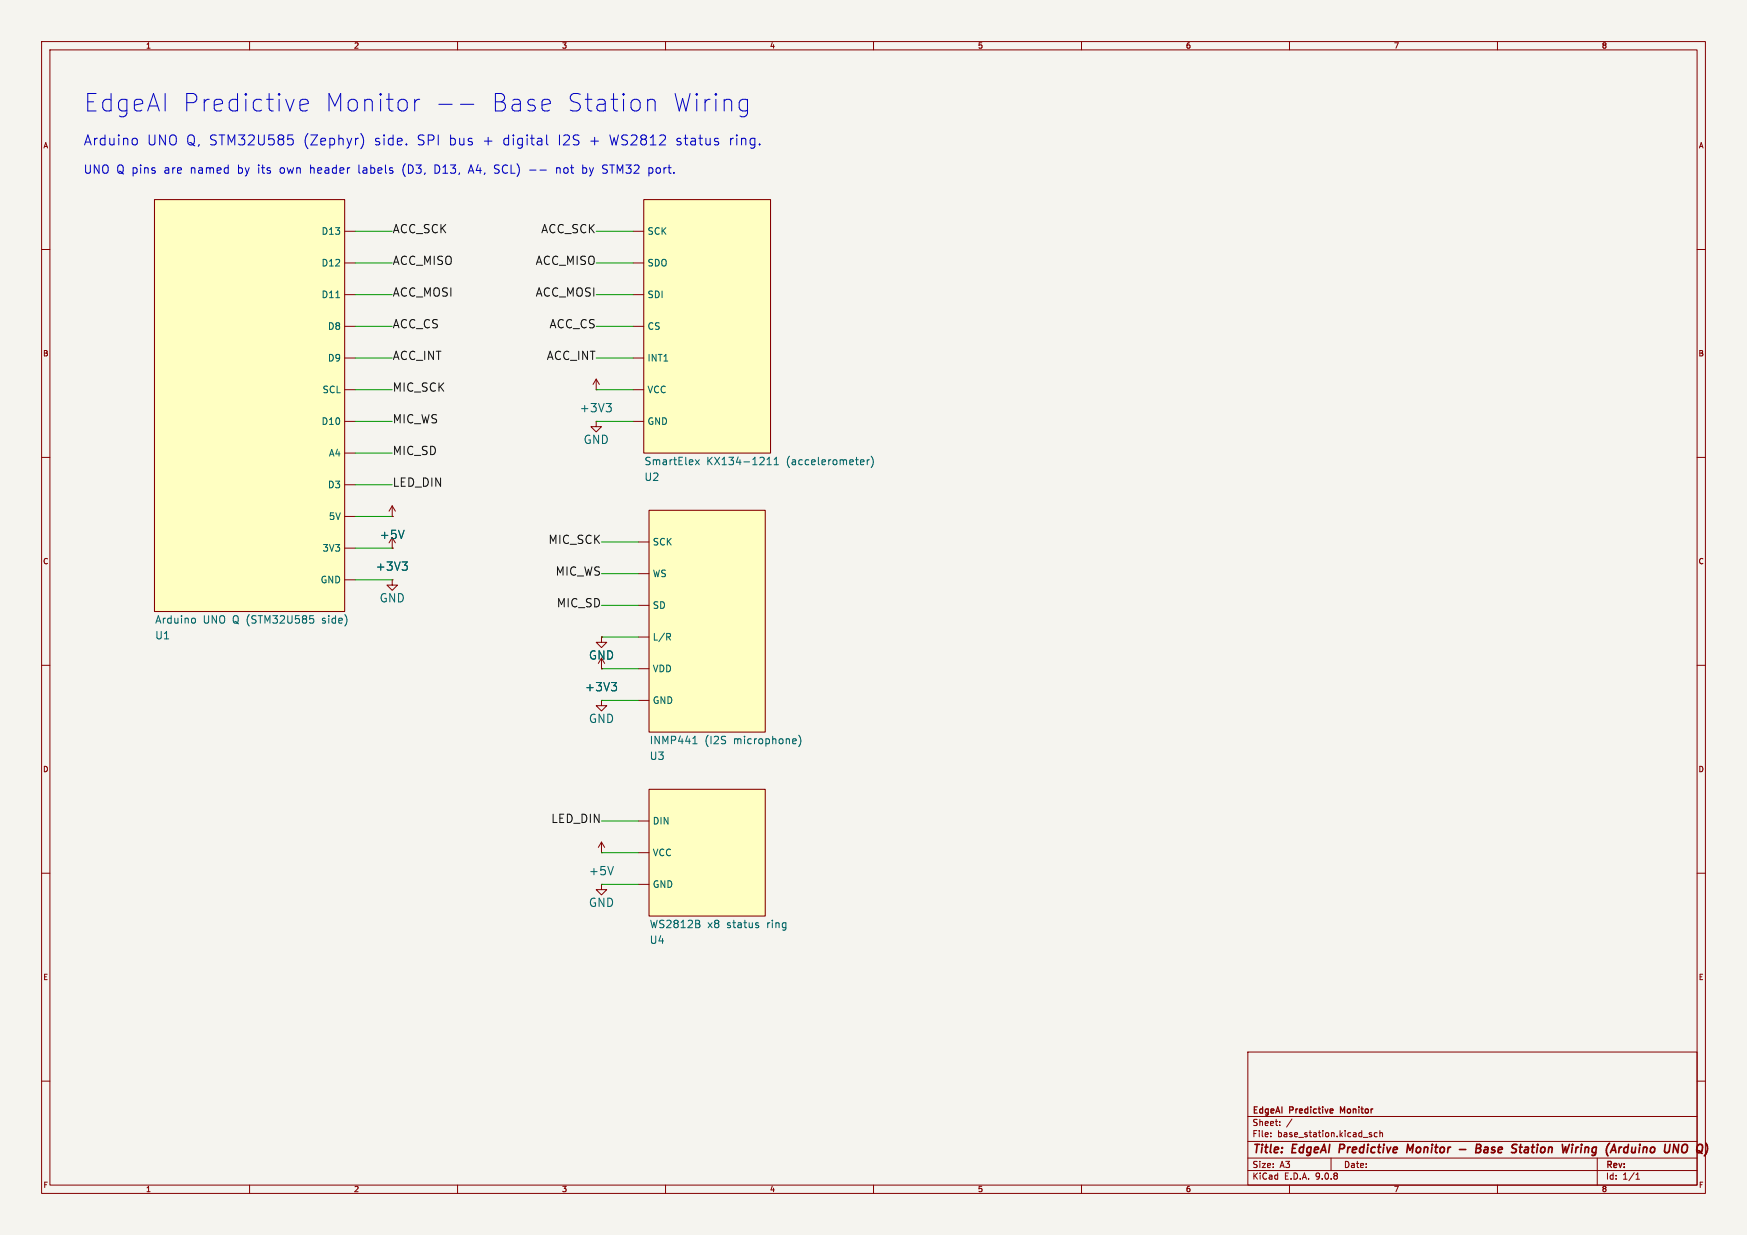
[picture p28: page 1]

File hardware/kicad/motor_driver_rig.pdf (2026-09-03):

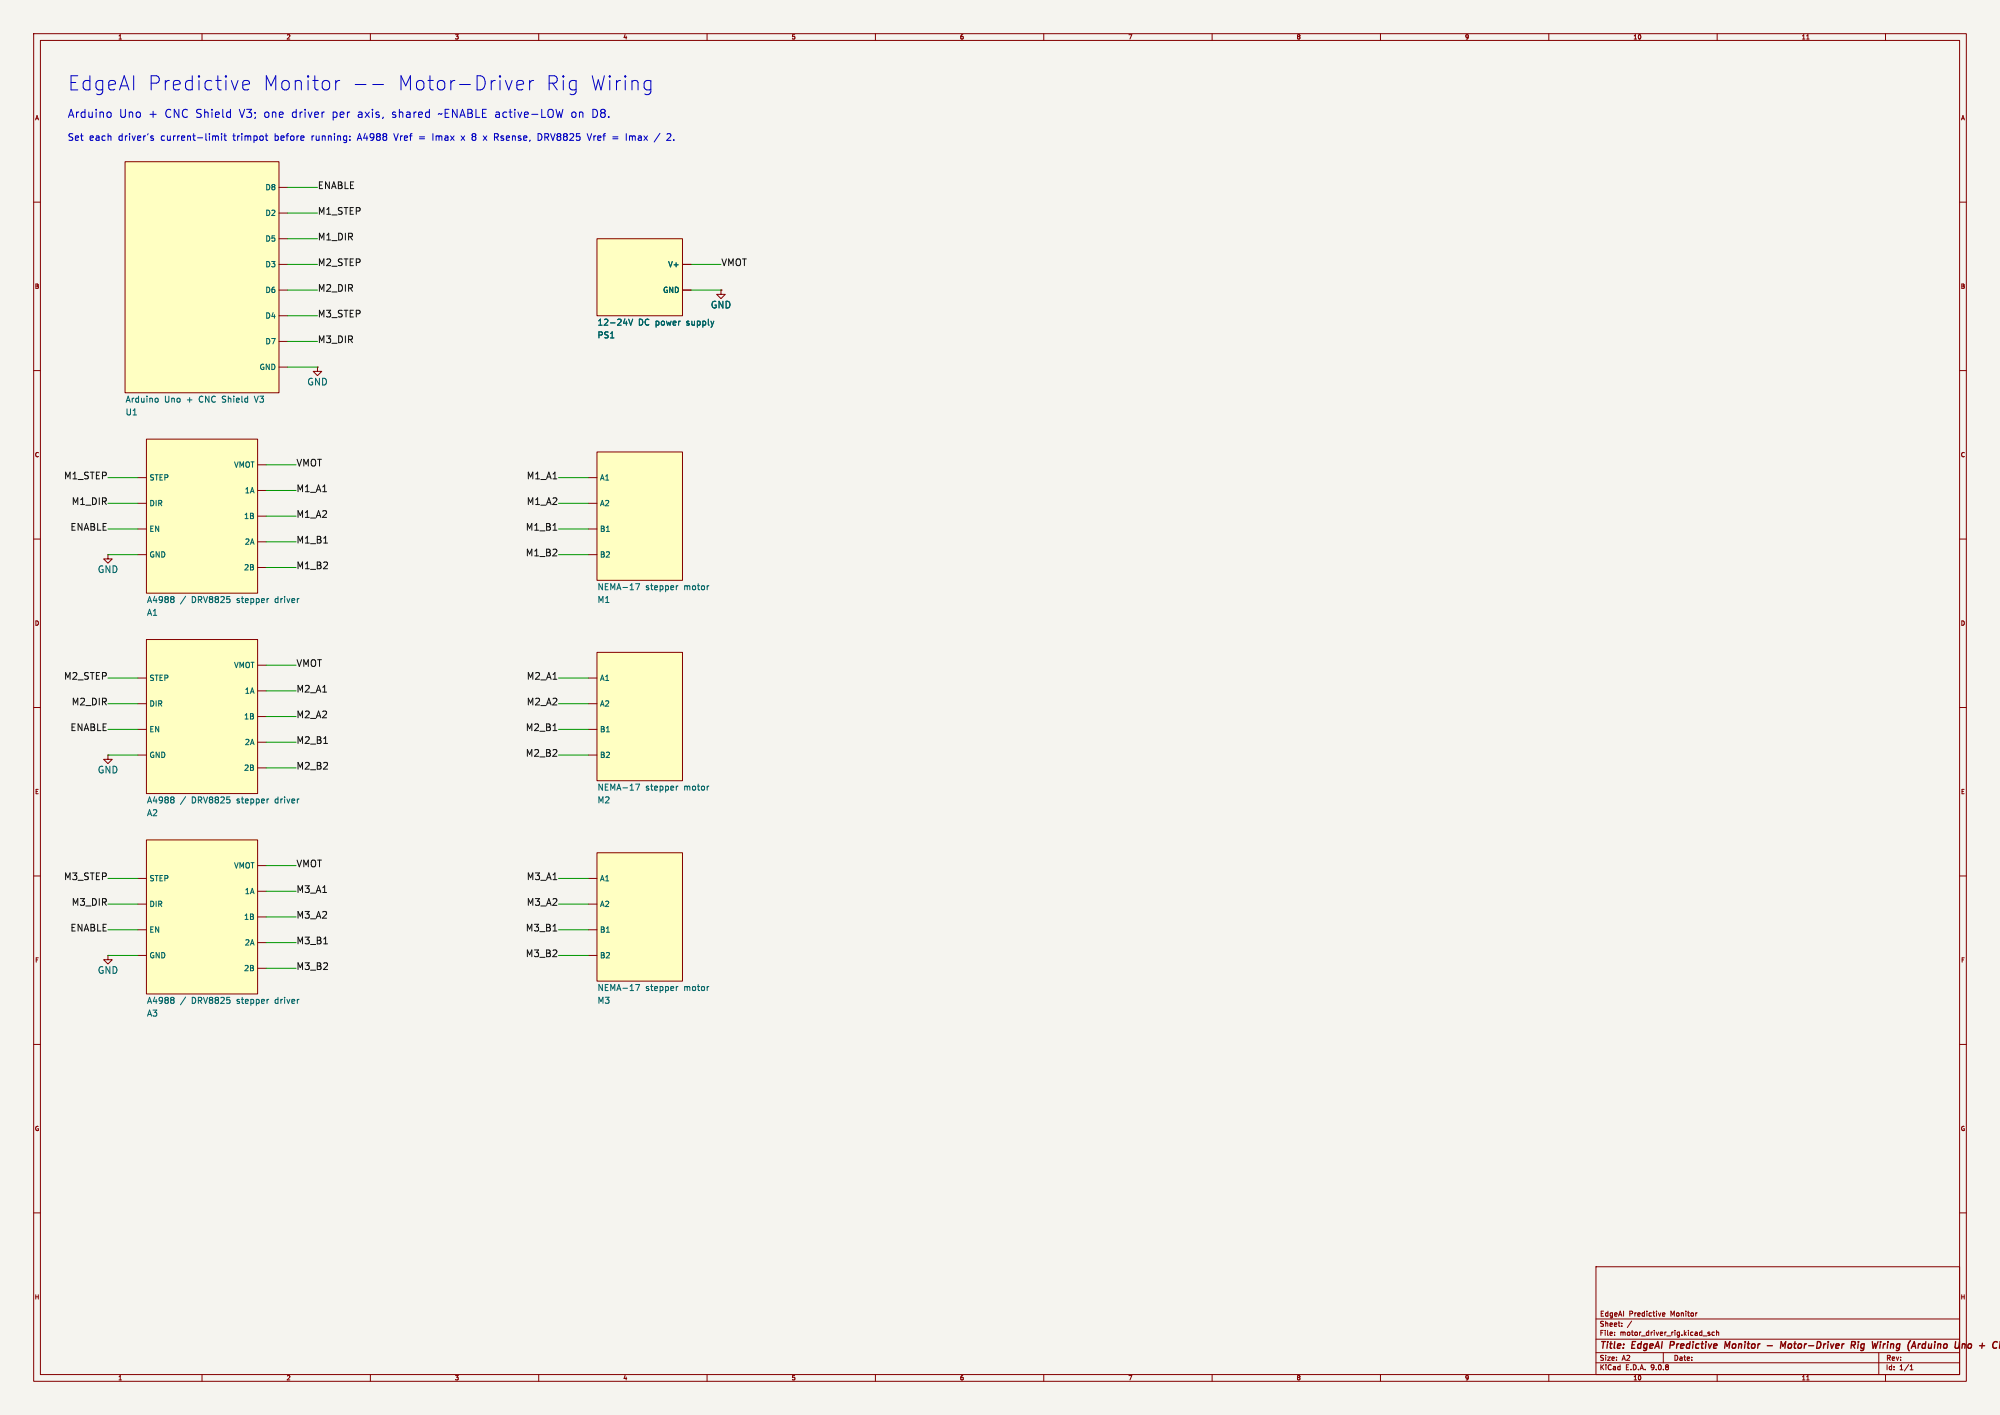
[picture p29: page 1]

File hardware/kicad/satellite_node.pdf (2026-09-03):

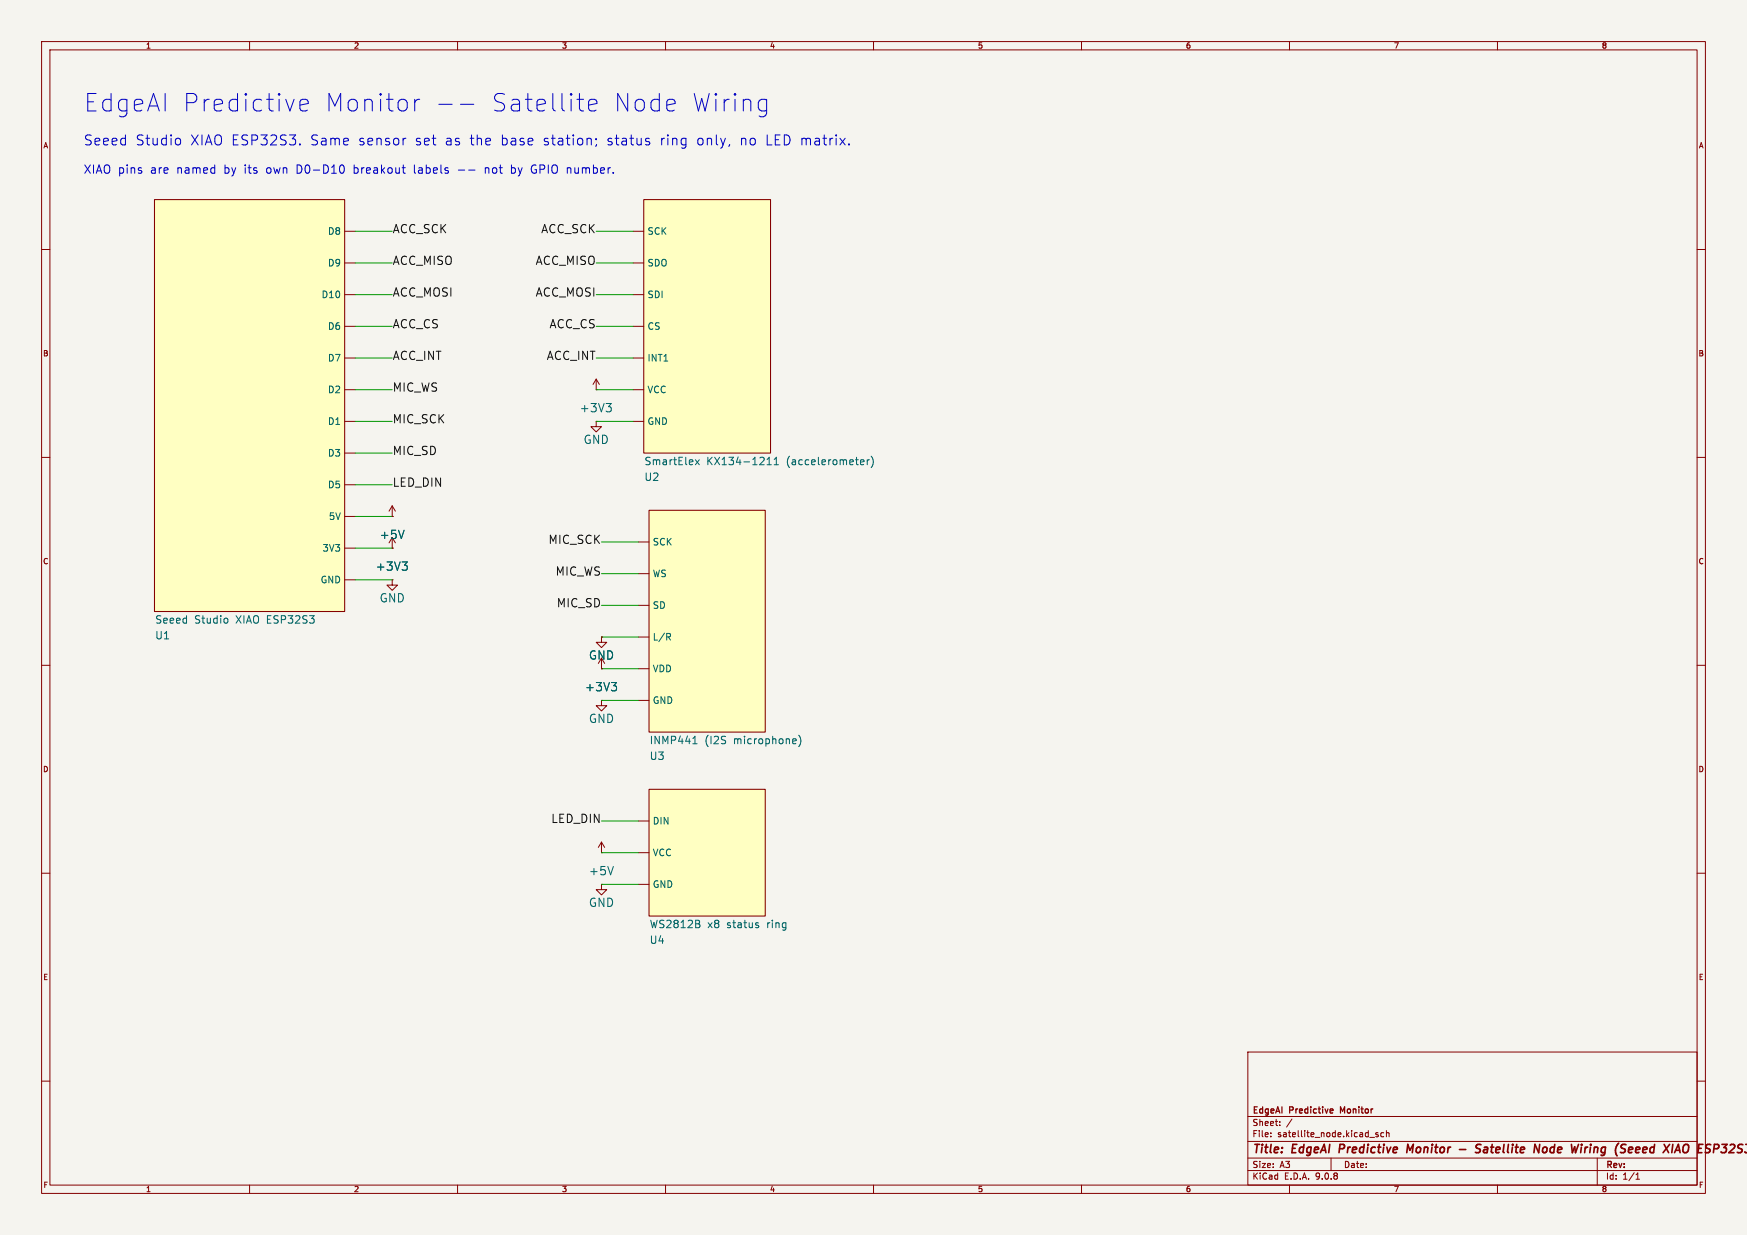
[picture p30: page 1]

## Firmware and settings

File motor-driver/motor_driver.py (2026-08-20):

#!/usr/bin/env python3
"""Host-side controller for the 3-motor stepper vibration rig.

This is the process that owns the rig on its host machine. It does three
things, each of which works without the other two:

  1. **Serves the control page.** `dashboard.html` is served from here rather
     than from a bare `python3 -m http.server`, so the page has somewhere to
     ask which motors are installed and whether one has been tripped.
  2. **Listens for machinery-protection trips** over MQTT and stops the named
     motor (`--mqtt-host`). One-way: nothing here can start a motor from the
     network.
  3. **Runs a scripted capture profile** (`--profile`) — baseline -> speed
     sweep -> injected fault, each phase printing a timestamped marker so a
     captured vibration stream can be aligned with the commanded state.

The firmware applies whatever RPM it's told IMMEDIATELY, with no ramp of its
own (see src/main.cpp) — so this script ramps every speed change itself via
Rig.ramp_to(), the same way dashboard.html does, instead of jumping straight
to a target that could stall a motor.

Requires pyserial (and paho-mqtt for --mqtt-host):
    pip install pyserial paho-mqtt

Examples:
    ./start_motor_driver.sh                          # everything defaulted (broker at epm-base.local)
    ./start_motor_driver.sh --mqtt-host uno-q.local  # broker at a different host
    ./start_motor_driver.sh --mqtt-host ''           # no broker at all
    python3 motor_driver.py --port COM5 --profile --baseline-rpm 90
"""

import argparse
import json
import math
import os
import struct
import sys
import threading
import time
from http.server import SimpleHTTPRequestHandler, ThreadingHTTPServer

try:
    import serial  # pyserial
except ImportError:
    sys.exit("pyserial not installed. Run: pip install pyserial")

# Every motor this rig is physically wired for -- the hardware's capability,
# fixed by src/main.cpp and the CNC shield's three driver slots. Which of them
# are actually installed and offered to the base station is a separate,
# runtime-editable question: see OutputSet.
MOTOR_IDS = (1, 2, 3)

# USB (vendor, product) IDs of the boards this rig's firmware runs on.
#
# Deliberately a whitelist of Uno-shaped boards rather than "anything with an
# Arduino vendor ID". On this bench the UNO Q base station is ALSO an
# Arduino-VID CDC device on /dev/ttyACM* (2341:0078, "UNO Q - epm-base"), and
# an autodetect that grabbed the first Arduino would open the monitoring
# board's port and start writing stepper commands into it.
UNO_USB_IDS = {
    (0x2341, 0x0043), (0x2341, 0x0001), (0x2341, 0x0243),  # Arduino Uno R3
    (0x2A03, 0x0043), (0x2A03, 0x0001),                    # Arduino SRL Uno
    (0x1A86, 0x7523),                                      # CH340 clone
    (0x0403, 0x6001),                                      # FTDI-based clone
}


def find_uno_port() -> str:
    """The port an Uno is on, when there is exactly one and no doubt about it.

    Raises RuntimeError otherwise -- with the list of what it actually saw.
    Guessing is worse than asking here: the wrong port is either a board that
    ignores the commands, or the base station being written to."""
    from serial.tools import list_ports

    ports = list(list_ports.comports())
    matches = [p for p in ports if (p.vid, p.pid) in UNO_USB_IDS]
    if len(matches) == 1:
        return matches[0].device

    # Only list USB serial devices in the error: a Linux host has eight
    # /dev/ttyS* legacy ports that are never the answer and only add noise.
    seen = [f"  {p.device}  {p.product or p.description}"
             + (f"  [{p.vid:04x}:{p.pid:04x}]" if p.vid else "")
             for p in ports if p.vid]
    detail = ("\n" + "\n".join(seen)) if seen else " (none)"
    if not matches:
        raise RuntimeError(
            f"couldn't find an Arduino Uno. USB serial devices seen:{detail}\n"
            f"Pass --port explicitly, e.g. --port /dev/ttyACM0.")
    raise RuntimeError(
        f"found {len(matches)} Uno-like boards, so which one is the rig is a "
        f"guess. USB serial devices seen:{detail}\nPass --port explicitly.")


RAMP_RPM_S = 150.0   # matches the firmware's old proven-safe ramp rate
RAMP_TICK_S = 0.1

# --- machinery-protection trip (docs/MOTOR_STOP_PLAN.md) ---------------
#
# The base station publishes [TYPE:1B][PAYLOAD] to epm/<node_id>/cmd. These
# two constants are a deliberate hand-rolled copy of
# base-station/python/common/wire_protocol.py's MqttMsgType.MOTOR_STOP and
# MOTOR_STOP_PAYLOAD_FMT: this script runs on the host laptop that owns the
# rig's USB port, a different machine entirely from the UNO Q the base-station
# package deploys to, so it can't import them. Same convention the ESP32
# satellite firmware already follows for the telemetry formats.
#
# wire_protocol.py is the source of truth. base-station/tests/
# wire_protocol_test.py asserts the exact bytes this copy expects, so the two
# can't drift silently.
MQTT_MSG_TYPE_MOTOR_STOP = 0x09
MOTOR_STOP_PAYLOAD_FMT = "<B"  # motor_idx, 1-based

# Every asset's command topic, not one node's. A trip is addressed by the
# motor_idx in its payload -- that is what identifies an output on this rig;
# the node_id in the topic is the *asset that faulted*, which is incidental
# here. Subscribing to a single node's topic (which this did, from a CLI arg)
# meant a second monitored asset's trip was published into the void, no matter
# which output it was mapped to (docs/UNIFIED_COMMISSIONING_PLAN.md S1.1/S3.2).
CMD_TOPIC_FILTER = "epm/+/cmd"

# This rig's own retained self-description, so the base station stops guessing
# how many outputs exist (S3.2). Published once on connect and retained, so a
# base station that starts later still receives it. JSON, unlike the binary
# command direction above: this is host-to-host, variable-length, and never on
# a hot path -- no MCU firmware parses it.
OUTPUTS_TOPIC_FMT = "epm/{node_id}/outputs"

# The broker lives on the UNO Q, and there are exactly two ways this host
# reaches it: straight to :1883 over the LAN, or through `adb forward
# tcp:11883 tcp:1883` when the board is in AP mode and has no LAN address --
# which is most of the time on this bench. Rather than make that a flag
# everyone has to remember, prefer the forwarded port when something is
# actually listening on it. Getting this wrong is silent: the rig connects to
# nothing, publishes no announce, and the base station goes on showing a stale
# retained motor list, which looks like a bug in the dashboard.
ADB_FORWARDED_MQTT_PORT = 11883
DEFAULT_MQTT_PORT = 1883


def default_mqtt_port(host: str) -> int:
    """The adb-forwarded port if it's live, else the standard one."""
    import socket

    if host in ("localhost", "127.0.0.1", "::1"):
        try:
            with socket.create_connection((host, ADB_FORWARDED_MQTT_PORT), timeout=0.4):
                return ADB_FORWARDED_MQTT_PORT
        except OSError:
            pass
    return DEFAULT_MQTT_PORT


def marker(label: str) -> None:
    print(f"[{time.strftime('%H:%M:%S')}] === {label} ===", flush=True)


class Rig:
    """The rig's motors, and whatever this process can do to them.

    `port=None` is the DEFAULT and the normal case, because the control page
    has always driven the motors over Web Serial from the browser -- and on
    the usual split setup (rig host in WSL, Chrome and the USB device on
    Windows) the browser is the only thing that can reach the Uno at all.
    Forwarding the device into WSL with usbipd doesn't help: it takes the port
    away from Chrome, and then the control page has nothing to connect to.

    So without a port this object is the rig's *bookkeeping* -- which motors
    are tripped, what speed each was last told -- and the control page applies
    the actual stop. With a port it also writes the bytes itself, which is
    what `--profile` and browser-less protection need.
    """

    def __init__(self, port: str = None, baud: int = 115200):
        self.port = port
        self.ser = None
        if port is not None:
            # 2 s settle: opening the port resets the Uno.
            self.ser = serial.Serial(port, baud, timeout=1)
            time.sleep(2.0)
        # Re-entrant, and it guards BOTH the serial writes and self.rpm:
        # once a trip listener thread exists, two threads issue commands on one
        # port. Unsynchronized writes interleave mid-line and the firmware's
        # single-char parser (src/main.cpp) reads the result as garbage.
        # Re-entrant because disable()/stop_motor() call motor() while holding
        # it, and both need to be atomic as a whole.
        self._lock = threading.RLock()
        if self.ser is not None:
            self._drain()
        self.rpm = {idx: 0.0 for idx in MOTOR_IDS}  # last RPM sent per motor
        # Motors stopped by a protection trip. Commands for these are refused
        # until clear_trip() -- see motor() below.
        self._tripped = set()

    @property
    def has_serial(self) -> bool:
        return self.ser is not None

    def _drain(self) -> None:
        while self.ser.in_waiting:
            self.ser.readline()

    def send(self, cmd: str) -> None:
        with self._lock:
            if self.ser is None:
                # No port here: the control page holds it. Every caller still
                # updates self.rpm / self._tripped around this, so the state
                # the page reads from /api/state stays correct and the page
                # applies the command. Silently dropping the write is the
                # whole point -- callers must not have to know which mode
                # they're in.
                return
            self.ser.write((cmd.strip() + "\n").encode())
            self.ser.flush()

    def motor(self, idx: int, rpm: float) -> None:
        with self._lock:
            # A tripped motor stays stopped until a human clears it. Without
            # this, run_profile()'s scripted ramps (or dashboard.html's ramp
            # tick) would cheerfully command the tripped motor back up to
            # speed on the very next tick, undoing the trip a second after it
            # landed. "Only a human restarts a machine" has to be enforced
            # here, at the one place that writes speeds, not just promised.
            if idx in self._tripped and abs(rpm) > 0.05:
                return
            self.send(f"{idx} {rpm:.1f}")
            self.rpm[idx] = rpm

    def stop_motor(self, idx: int) -> None:
        """Machinery-protection trip: stop ONE motor, leaving the others
        running.

        Sends "<idx> 0" rather than "d", because the CNC shield has a single
        shared ~ENABLE -- "d" would cut all three. A stepper commanded to 0 RPM
        stops turning (and so stops producing vibration, which is what lets the
        base station confirm the trip) while still holding position. "d" is
        only safe once every motor is already at zero, which is the same rule
        dashboard.html's refreshEnergize() follows."""
        with self._lock:
            self._tripped.add(idx)
            self.rpm[idx] = 0.0
            self.send(f"{idx} 0.0")
            if all(abs(v) <= 0.05 for v in self.rpm.values()):
                self.send("d")

    def clear_trip(self, idx: int) -> None:
        """Re-arm a tripped motor. Deliberately never called from the trip
        listener -- only from a human path."""
        with self._lock:
            self._tripped.discard(idx)

    def tripped(self) -> list:
        """Which motors are currently held stopped by a trip.

        Read by the control server so dashboard.html can show it. Until this
        existed, a trip was visible only as a line in this script's terminal:
        the control page went on showing the motor as RUNNING at its old
        speed, because nothing ever told it otherwise. Worse, its ramp tick
        was still free to command that motor back up the moment anyone
        touched a slider."""
        with self._lock:
            return sorted(self._tripped)

    def ramp_to(self, targets: dict, rate: float = RAMP_RPM_S, tick: float = RAMP_TICK_S) -> None:
        """Ramp the given {motor_id: target_rpm} from their last-sent RPM,
        blocking until every motor in `targets` has arrived.

        A tripped motor is treated as already arrived. It must be: motor()
        refuses to move it, so waiting for it to reach a nonzero target would
        never finish -- a trip landing mid-profile would hang this loop (and
        the whole script) forever instead of letting the remaining motors
        carry on."""
        # Advance by ELAPSED time, not by "one loop pass = one step". Each pass
        # costs tick PLUS however long the serial writes took, so a fixed
        # per-pass delta always ramped slower than `rate` asked for -- and the
        # more motors in `targets`, the slower it got. The catch-up is capped at
        # two ticks so a scheduling hiccup resumes the ramp instead of issuing
        # one big jump, which is the stall this ramp exists to prevent.
        last = time.monotonic() - tick   # first pass gets one full tick's worth
        while True:
            now = time.monotonic()
            max_delta = rate * min(now - last, tick * 2)
            last = now
            done = True
            for idx, target in targets.items():
                if idx in self._tripped:
                    continue
                cur = self.rpm[idx]
                if abs(target - cur) > 0.05:
                    done = False
                    step = math.copysign(min(abs(target - cur), max_delta), target - cur)
                    self.motor(idx, cur + step)
            if done:
                break
            time.sleep(tick)
        for idx, target in targets.items():  # snap exactly to the target
            if idx in self._tripped:
                continue
            self.motor(idx, target)

    def enable(self) -> None:
        self.send("e")

    def disable(self) -> None:
        # Zero every motor before cutting power, never just "d". The firmware
        # keeps each motor's last commanded speed, and the shield's single
        # shared ~ENABLE means the next "e" re-applies all of them at once --
        # so a disable-without-zero leaves the whole rig armed to jump back to
        # speed the instant anything re-enables it.
        with self._lock:
            for idx in MOTOR_IDS:
                # Bypasses motor()'s tripped-motor refusal: zero is the one
                # command a tripped motor must always accept.
                self.send(f"{idx} 0.0")
                self.rpm[idx] = 0.0
            self.send("d")

    def close(self) -> None:
        if self.ser is None:
            return
        try:
            self.disable()
        finally:
            self.ser.close()


class OutputSet:
    """Which motors are installed on this rig *right now*.

    Not the same question as MOTOR_IDS. MOTOR_IDS is what the shield could
    drive; this is what a human has actually bolted down and wants offered to
    the base station as a trip output. A rig wired for three motors where only
    one drives a monitored asset has exactly one meaningful trip output, and
    putting the other two in front of an operator invites mapping a sensor to
    a motor that has nothing to do with it.

    Mutable at runtime, and that is the point: adding a motor on the control
    page re-announces, so a new trip output appears in the base station's
    setup without restarting anything. Subscribers are notified on change --
    TripListener registers its announce here.
    """

    def __init__(self, outputs=MOTOR_IDS):
        self._lock = threading.Lock()
        self._outputs = self._clean(outputs)
        self._listeners = []

    @staticmethod
    def _clean(outputs) -> tuple:
        return tuple(sorted({int(idx) for idx in outputs}))

    def get(self) -> tuple:
        with self._lock:
            return self._outputs

    def set(self, outputs) -> tuple:
        """Replace the installed set. Raises ValueError for anything the rig
        isn't wired for -- an offered output the rig would then refuse is the
        one mapping that looks armed and does nothing."""
        cleaned = self._clean(outputs)
        unknown = [idx for idx in cleaned if idx not in MOTOR_IDS]
        if unknown:
            raise ValueError(f"motors {unknown} are not on this rig {list(MOTOR_IDS)}")
        with self._lock:
            self._outputs = cleaned
            listeners = list(self._listeners)
        # Outside the lock: an announce publishes over the network, and a
        # listener that blocks must not freeze every other reader of this set.
        for callback in listeners:
            callback(cleaned)
        return cleaned

    def subscribe(self, callback) -> None:
        with self._lock:
            self._listeners.append(callback)
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

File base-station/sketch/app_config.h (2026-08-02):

#ifndef APP_CONFIG_H_
#define APP_CONFIG_H_

/*
 * Single place for every module's tunable "policy" knobs - sample rates,
 * bin counts, thread priorities, tick/epoch periods, the Bridge baud, and
 * the benchmark toggle. Mirrors the old repo's mcu/src/app_config.h intent
 * (edgeai-predictive-monitor-unoq), extended here to also centralize thread
 * priorities: priority mistakes (mic's busy-poll starving Bridge, the
 * fuser/Bridge-update-thread tie) were this port's two worst hardware bugs
 * (see docs/PROGRESS.md), so every priority now lives in one file where they
 * can be eyeballed together instead of six.
 *
 * Deliberately NOT moved here: pin assignments, register maps, wire-format
 * constants (chunk size/magic byte), stack sizes, and derived math (e.g.
 * MIC_FFT_LEN = MIC_FFT_BIN_COUNT * 4) - those are implementation details of
 * one file, not cross-module policy, and stay defined locally (computed off
 * this header's base constants where they depend on one).
 */

/* Compile-time switch for the per-stage throughput counters + periodic
 * "get_bench_stats" Bridge summary (mic_sampler.cpp/accel_sampler.cpp/
 * fuser.cpp), ported from the old repo's BENCHMARK_STATS_ENABLED /
 * docs/Sensor_Throughput_Tuning_Plan.md Phase 0. Left on (1) here, unlike
 * the old repo's default-off: this project wants these numbers pollable
 * from the MPU dashboard on an ongoing basis (and eventually from satellite
 * nodes too), not just during a one-off tuning pass, so there's no "done
 * tuning, flip it off" moment the way the old repo had. Flip to 0 to compile
 * all of it out (no counters, no get_bench_stats provider) if that changes. */
#define BENCHMARK_STATS_ENABLED 1

/* --- Sample rates / bin counts ------------------------------------------
 * Both are unique-bin counts (excl. DC), not FFT length - each file derives
 * its own *_FFT_LEN locally (mic: *4, accel: *2 - see mic_sampler.cpp's
 * MIC_FFT_BIN_COUNT comment for why the multiplier differs). */
#define MIC_FFT_BIN_COUNT 512
#define ACCEL_FFT_BIN_COUNT 512
/* KX134 output data rate. Raised from the original 1600Hz baseline toward
 * maximizing detectable vibration frequency (Nyquist = ODR/2), but NOT all
 * the way to the KX134-1211's 25600Hz hardware ceiling: that was tried and
 * confirmed (2026-07-21 A/B test, live hardware) to stall the SPI/Bridge
 * telemetry pipeline entirely (frames_ok stuck at 0) - almost certainly
 * accel_sampler_thread (priority 3, above Bridge's 5) no longer yielding
 * enough at that rate and starving Bridge, this board's #1 recurring failure
 * mode (see accel_sampler.cpp's header comment / rpc-transport project notes).
 * 12800Hz (8x original, Nyquist=6400Hz) is a deliberate step back from that
 * ceiling to leave headroom - see accel_sampler.cpp's
 * KX134_ODCNTL_OSA_12800HZ. Revisit lower (or fix the thread-priority root
 * cause) if this also proves unstable under sustained load. */
#define ACCEL_ODR_HZ 12800

/* Bridge's 256-byte round-trip ceiling forces both get_*_spectrum views down
 * to an average-pooled bucket count - same value/reasoning in both samplers. */
#define MIC_SPECTRUM_BINS 32
#define ACCEL_SPECTRUM_BINS 32

/* Wire resolution for the fault-detection model's feature vector (mic +
 * per-axis accel spectra fuser.cpp sends), distinct from ACCEL_SPECTRUM_BINS/
 * MIC_SPECTRUM_BINS above (that pair is the legacy 32-bin Bridge-RPC view,
 * unrelated). Chosen via tools/offline_experiment.py's sweep against real
 * captures (axis=separate bins=128 mic_bins=128 +
 * scalars=rms+kurtosis+std+peak+crest_factor+skewness -> input_dim=536,
 * +38.5 sigma worst-case fault separation, docs/SENSOR_TELEMETRY_FRAME_PLAN.md).
 * Pooling to this many buckets happens in fuser.cpp right before the wire
 * write and leaves the native FFT window (and therefore compute_scalars()'s
 * time-domain inputs) untouched - only the spectrum's wire bin depth shrinks. */
#define FUSER_MODEL_SPECTRUM_BINS 128
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

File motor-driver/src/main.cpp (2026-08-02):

/*
 * main.cpp — motor-driver firmware
 * -----------------------------------------------------------------------------
 * Three-stepper "rotating machine under test" for edgeai-predictive-monitor.
 * The Uno only knows "spin this motor at this RPM, right now" — it does
 * NOT ramp. Any acceleration/deceleration profile (so a motor doesn't stall
 * jumping straight to a high speed) is the host's job: dashboard.html or
 * motor_driver.py send a fast stream of intermediate RPM commands. Keeping the
 * firmware this dumb means new ramp/speed behavior is a dashboard/script edit,
 * not a re-flash.
 *
 * Requires the AccelStepper library, used here only for step-pulse generation
 * (setSpeed()/runSpeed()), not its acceleration machinery.
 *
 * Serial protocol (115200 baud, newline-terminated commands):
 *   1 <rpm>     set motor 1 (X) speed in RPM,  e.g.  "1 120"
 *   2 <rpm>     set motor 2 (Y) speed in RPM,  e.g.  "2 90"
 *   3 <rpm>     set motor 3 (Z) speed in RPM,  e.g.  "3 60"
 *   b <rpm>     set ALL THREE motors,          e.g.  "b 90"
 *   e           enable drivers (energize ALL THREE — one shared line)
 *   d           disable drivers (coast ALL THREE)
 *   s           print status
 *   h           print help
 *
 * Speed commands (1/2/3/b) reply with nothing — see handleCommand() for why.
 * Only e/d/s/h print.
 *
 * There is no per-motor enable: the shield wires one ~ENABLE to all three
 * drivers. To idle a single motor, command it "N 0" and leave the others
 * running. Note this means `e` re-energizes every driver at whatever speed it
 * was last told, so a host that wants motors stopped must send "N 0" for each
 * one — not just `d`.
 *
 * Negative RPM reverses direction. RPM is clamped to +/-RPM_MAX (~1200 RPM at
 * full step). A commanded speed applies IMMEDIATELY — no on-device ramp — so
 * a large jump at high RPM can stall the motor; ramp from the host instead.
 * -----------------------------------------------------------------------------
 */

#include <AccelStepper.h>

// ---- CNC Shield V3 pin map --------------------------------------------------
// Standard Protoneer/GRBL mapping. Note there is exactly ONE ~ENABLE line
// shared by all three driver sockets — the hardware has no per-motor enable,
// so "stopping" one motor means commanding it to 0 RPM, and `d` cuts all three.
constexpr uint8_t EN_PIN = 8;   // shared driver enable, ACTIVE LOW (LOW = drivers ON)
constexpr uint8_t M1_STEP = 2;  // X STEP
constexpr uint8_t M1_DIR  = 5;  // X DIR
constexpr uint8_t M2_STEP = 3;  // Y STEP
constexpr uint8_t M2_DIR  = 6;  // Y DIR
constexpr uint8_t M3_STEP = 4;  // Z STEP
constexpr uint8_t M3_DIR  = 7;  // Z DIR

// ---- Motor / motion configuration ------------------------------------------
constexpr int STEPS_PER_REV = 200;   // 1.8 deg motor = 200 full steps/rev
// MUST match the MS1/MS2/MS3 jumpers on the shield (A4988 driver table):
// none=1, MS1=2, MS2=4, MS1+MS2=8, all three (M0/M1/M2 jumpered)=16.
constexpr int MICROSTEP = 1;         // all jumpers removed -> full step

// Max pulse rate the Uno can reliably emit per motor. Bench-verified at
// 4000 sps for 2 motors; not yet re-verified with a 3rd motor sharing the
// loop (runSpeed() is cheap per call, so this should hold — confirm on real
// hardware before trusting it at the very top of the range).
constexpr float MAX_SPS = 4000.0;

// True achievable RPM ceiling at the current microstep setting, given MAX_SPS.
constexpr float RPM_MAX     = MAX_SPS * 60.0 / (STEPS_PER_REV * MICROSTEP); // ~1200 RPM at full step
constexpr float RPM_DEFAULT = 0.0;   // startup speed for all motors — host ramps up from here

AccelStepper m1(AccelStepper::DRIVER, M1_STEP, M1_DIR);
AccelStepper m2(AccelStepper::DRIVER, M2_STEP, M2_DIR);
AccelStepper m3(AccelStepper::DRIVER, M3_STEP, M3_DIR);

float rpm1 = 0.0, rpm2 = 0.0, rpm3 = 0.0;
bool  enabled = false;

// RPM -> steps per second for the current microstep setting.
float rpmToSps(float rpm) {
  return rpm / 60.0 * STEPS_PER_REV * MICROSTEP;
}

float clampRpm(float rpm) {
  if (rpm >  RPM_MAX) return  RPM_MAX;
  if (rpm < -RPM_MAX) return -RPM_MAX;
  return rpm;
}

void setEnabled(bool on) {
  enabled = on;
  digitalWrite(EN_PIN, on ? LOW : HIGH);  // active LOW
}

// Commands motor m to the given RPM immediately (no ramp) via setSpeed(),
// which runSpeed() in loop() turns into evenly-spaced step pulses.
void applyRpm(AccelStepper &m, float &store, float rpm) {
  store = clampRpm(rpm);
  m.setSpeed(rpmToSps(store));
}

void printStatus() {
  Serial.print(F("[status] drivers="));
  Serial.print(enabled ? F("ON ") : F("OFF"));
  Serial.print(F("  m1="));
  Serial.print(rpm1, 1);
  Serial.print(F(" RPM  m2="));
  Serial.print(rpm2, 1);
  Serial.print(F(" RPM  m3="));
  Serial.print(rpm3, 1);
  Serial.print(F(" RPM  microstep=1/"));
  Serial.println(MICROSTEP);
}

void printHelp() {
  Serial.println(F("commands: '1 <rpm>' '2 <rpm>' '3 <rpm>' 'b <rpm>' 'e' 'd' 's' 'h'"));
  Serial.print(F("  negative rpm reverses; rpm clamped to +/-"));
  Serial.println(RPM_MAX, 0);
  Serial.println(F("  no on-device ramp: speed changes apply immediately"));
}

void setup() {
  Serial.begin(115200);

  pinMode(EN_PIN, OUTPUT);
  setEnabled(true);            // energize on boot

  m1.setMaxSpeed(MAX_SPS);
  m2.setMaxSpeed(MAX_SPS);
  m3.setMaxSpeed(MAX_SPS);
  applyRpm(m1, rpm1, RPM_DEFAULT);
  applyRpm(m2, rpm2, RPM_DEFAULT);
  applyRpm(m3, rpm3, RPM_DEFAULT);

  Serial.println(F("=== motor-driver ready ==="));
  printHelp();
  printStatus();
}

// Parse one newline-terminated command line.
void handleCommand(const String &line) {
  String s = line;
  s.trim();
  if (s.length() == 0) return;

  char cmd = s.charAt(0);
  float arg = s.substring(1).toFloat();

  switch (cmd) {
    // Speed commands answer with SILENCE, deliberately. A status line is ~72
    // chars, which overflows the 64-byte serial TX buffer and makes
    // Serial.print() block until it drains — and that stalls loop(), starving
    // runSpeed() for ALL THREE motors. During a host ramp that's ~30
    // speed commands/second, so echoing here made every motor stutter audibly
    // whenever any one motor changed speed. Use 's' to read state instead.
    case '1':
      applyRpm(m1, rpm1, arg);
      break;
    case '2':
      applyRpm(m2, rpm2, arg);
      break;
    case '3':
      applyRpm(m3, rpm3, arg);
      break;
    case 'b':
    case 'B':
      applyRpm(m1, rpm1, arg);
      applyRpm(m2, rpm2, arg);
      applyRpm(m3, rpm3, arg);
      break;
    case 'e':
    case 'E':
      setEnabled(true);
      printStatus();
      break;
    case 'd':
    case 'D':
      setEnabled(false);
      printStatus();
      break;
    case 's':
    case 'S':
      printStatus();
      break;
    case 'h':
    case 'H':
    case '?':
      printHelp();
      break;
    default:
      Serial.print(F("[err] unknown command: "));
      Serial.println(s);
      printHelp();
      break;
  }
}
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

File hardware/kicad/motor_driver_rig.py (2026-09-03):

#!/usr/bin/env python3
from gen import Part, Schematic, stack_column, write_pro

sch = Schematic("EdgeAI Predictive Monitor - Motor-Driver Rig Wiring (Arduino Uno + CNC Shield V3)", paper="A2")

# Pins are named the way the Arduino Uno underneath names them (D2-D8) --
# the CNC Shield's own X/Y/Z STEP+DIR silkscreen is just a relabelling of
# these header pins, and the header number is what you probe. Assignment is
# from motor-driver/src/main.cpp: EN=8, X=2/5, Y=3/6, Z=4/7.
HUB = Part(
    "epm:ARDUINO_UNO_CNC", "U", "Arduino Uno + CNC Shield V3",
    right=["D8", "D2", "D5", "D3", "D6", "D4", "D7", "GND"],
    width=45.72,
)
DRIVER = Part(
    "epm:STEPPER_DRIVER", "A", "A4988 / DRV8825 stepper driver",
    left=["STEP", "DIR", "EN", "GND"],
    right=["VMOT", "1A", "1B", "2A", "2B"],
    width=33.02,
)
MOTOR = Part(
    "epm:NEMA17", "M", "NEMA-17 stepper motor",
    left=["A1", "A2", "B1", "B2"],
    width=25.4,
)
PSU = Part(
    "epm:PSU_DC", "PS", "12-24V DC power supply",
    right=["V+", "GND"],
    width=25.4,
)

# 2 columns, both filled every row: col 1 is the Uno then its 3 drivers,
# col 2 is the PSU then their 3 motors -- driver/motor land in the same row
# so their labels (VMOT, M1_A1, ...) still face each other across the gap.
row_heights = [max(HUB.height, PSU.height)] + [max(DRIVER.height, MOTOR.height)] * 3
hub_y, driver1_y, driver2_y, driver3_y = stack_column(48, row_heights)
psu_y, motor_y = hub_y, [driver1_y, driver2_y, driver3_y]
COL1, COL2 = 60, 190

sch.place(HUB, "U1", COL1, hub_y, {
    "D8": "ENABLE", "GND": "PWR:GND",
    "D2": "M1_STEP", "D5": "M1_DIR",
    "D3": "M2_STEP", "D6": "M2_DIR",
    "D4": "M3_STEP", "D7": "M3_DIR",
})

sch.place(PSU, "PS1", COL2, psu_y, {
    "V+": "VMOT", "GND": "PWR:GND",
})

for idx, y in zip((1, 2, 3), motor_y):
    sch.place(DRIVER, f"A{idx}", COL1, y, {
        "STEP": f"M{idx}_STEP",
        "DIR": f"M{idx}_DIR",
        "EN": "ENABLE",
        "GND": "PWR:GND",
        "VMOT": "VMOT",
        "1A": f"M{idx}_A1", "1B": f"M{idx}_A2",
        "2A": f"M{idx}_B1", "2B": f"M{idx}_B2",
    })
    sch.place(MOTOR, f"M{idx}", COL2, y, {
        "A1": f"M{idx}_A1", "A2": f"M{idx}_A2",
        "B1": f"M{idx}_B1", "B2": f"M{idx}_B2",
    })

sch.note("EdgeAI Predictive Monitor -- Motor-Driver Rig Wiring", 20, 25, size=4.2)
sch.note("Arduino Uno + CNC Shield V3; one driver per axis, shared ~ENABLE active-LOW on D8.", 20, 34, size=2.4)
sch.note("Set each driver's current-limit trimpot before running: A4988 Vref = Imax x 8 x Rsense, DRV8825 Vref = Imax / 2.", 20, 41, size=2.0)

open("motor_driver_rig.kicad_sch", "w").write(sch.render())
write_pro("motor_driver_rig.kicad_pro", sch)
print("wrote motor_driver_rig.kicad_sch + motor_driver_rig.kicad_pro")

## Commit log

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2026-07-14 base-station: config consolidation, bench module, provider-registration ordering
    Consolidate every module's tunables (bin counts, thread priorities, tick/epoch
    periods, BRIDGE_BAUD) into sketch/app_config.h and remove the old
    bridge_config.h. Add sketch/bench.{h,cpp} exposing get_bench_stats over Bridge,
    backed by per-stage *_get_stats() accessors in mic/accel/fuser. Samplers now
    publish their full 512-bin float32 spectra for the fuser
    (*_copy_full_spectrum + metadata accessors).
    Order setup() so every Bridge.provide() provider registers before fuser_start()
    begins the notify stream (matrix->rgb->accel->mic->bench->fuser, fuser last).
    This prevents provider registrations from being lost to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
    [accel_sampler.cpp, app_config.h, fuser.cpp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]
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2026-07-14 base-station: SPI3-slave + GPDMA1 TX bring-up spike, disabled by default
    Register-level SPI3 slave + GPDMA1 TX link (spi_link.cpp) proving out the
    MCU<->MPU dedicated SPI bus, plus the host-side plumbing needed to reach it
    from the app container: a root-owned spi_bridge.py daemon (spi-bridge.service,
    installed by provision-spi.sh) that owns /dev/spidev0.0 and re-exposes it over
    /dev/spi-link.sock, since the container's device-cgroup allowlist blocks
    spidev directly. tests/spi_link_test.py validates the known pattern over that
    socket.
    spi_link_start() is left commented out in sketch.ino (last known-good board
    config) - the register-level implementation is believed correct (every
    constant tra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
    [app_config.h, sketch.ino, spi_bridge.py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]
2026-07-14 base-station: revert UART Bridge baud 1M -> 115200 library default
    Baud was raised in 3cb7e1c to carry the fuser's full-res float32 stream, but
    that's not what wedges the link - the recurring Bridge wedge is a msgpack
    framing desync on the continuous notify stream, reproduced identically at 1M
    and 2M baud (docs/progress2.md section 2). The actual fix is moving the bulk
    stream off the UART onto the dedicated SPI bus (spi_link.{h,cpp}), leaving
    this link as RPC/control-only, for which 115200 is ample. Removed the
    on-device 99-baud.conf systemd override so the router matches
    (provision-baud.sh kept for reference/rollback, no longer applied).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
    [app_config.h, fuser.cpp]
2026-07-14 base-station: re-test spi_link_start() on a clean link - hang reproduced
    Re-enabled spi_link_start() after reverting UART baud and confirming a clean
    board (full reboot, 3 clean Bridge.call()s, zero framing-desync errors) -
    this rules out the 4.6 confound (a degraded link from hours of prior stress).
    The hang reproduced anyway, twice, with the same silent-death signature as
    the earlier SPI1/Zephyr-API attempt (4.3): every Bridge provider stops
    responding, zero "invalid packet" desync errors in the router log. So the
    register-level SPI3+GPDMA1 rewrite (4.5) does not fix the hang - whatever's
    wrong is shared between both SPI implementation attempts, not specific to
    the Zephyr SPI subsystem. Ro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
    [sketch.ino]
2026-07-14 base-station: SPI link working end-to-end - 40/40 frames, all hangs root-caused
    - spi_link: priority 3->6, per-arm GPDMA+SPI flag clears (latched EOT gated
    every re-arm), RPC-triggered spi_arm handshake, error counters + magic
    diag block for SWD post-mortems
    - fuser: k_yield->k_msleep(1) on overrun; disabled on UART@115200 (one frame
    = ~407ms of UART vs 64ms epoch -> notify busy-spin starved the system)
    - mic: clear latched DMA flags per block (was fast-exiting at 188fps on
    stale TC, ~100% CPU); unmasked pre-existing dead SAI capture (sr=0x0) - open
    - docs/progress2.md 4.8: SWD-via-onboard-OpenOCD debugging method + full
    root-cause chain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
    [app_config.h, fuser.cpp, mic_sampler.cpp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]
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2026-07-15 base-station: fix mic/SAI capture - NODIV=1 + busy-poll the RX DMA
    Two stacked bugs kept the mic serving all-zero spectra (docs/progress2.md §6):
    #1 (NODIV, §6.2): mic_sampler_init_sai() wrote NODIV=0 in CR1 while MCKDIV=25
    was derived from the NODIV=1 bit-clock formula, so the SAI clock generator
    never started (SR=0x0, FIFO never filled). Fixed by OR-ing in SAI_xCR1_NODIV.
    #2 (OVR-latch, §6.3): with the SAI producing, the RX GPDMA still stalled -
    a WFI idle during the capture thread's k_msleep(2) let the SAI RX FIFO
    overrun, and OVR latching halts the DMA requests for the rest of the block
    (root-caused via live SWD: a debug halt / forced run-mode kept the D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
    [mic_sampler.cpp, sketch.ino]
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2026-07-16 base-station: drive RGB ring via SPI1+GPDMA instead of irq_lock bit-bang
    The old irq_lock()+busy-wait WS2812 bit-bang had two hardware-confirmed
    bugs: CONST yellow (and any color with adjacent 0xFF wire bytes) rendered
    green due to per-bit timing jitter, and BREATHE/STROBE held irq_lock for
    ~240us every 20ms from a thread above Bridge's priority, overrunning the
    115200 RPC UART and crashing Bridge's read loop (msgpack framer desync).
    Replaced with SPI1 master TX (MOSI-only, PA12/AF5) + GPDMA1: each WS2812
    bit becomes one SPI byte clocked at 5MHz, DMA-streamed with no CPU
    involvement and no IRQ lock. Fixes both bugs - verified with
    tests/display_rgb_test.py running all 6 steps (incl. breathe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
    [rgb_display.cpp]
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2026-07-16 base-station: drive RGB ring via TIM3+GPDMA instead of SPI1, fixing pixel-0 glitch
    SPI1's CSTART cold-started the clock generator every frame, which was the
    suspected cause of a pixel-0-only color glitch left over from the previous
    SPI1+GPDMA1 rewrite (74ca11e). Switched to TIM3_CH3 PWM + GPDMA1, with TIM3
    free-running continuously (enabled once, never per-frame) and DMA fed by its
    UPDATE event - no per-frame clock restart to glitch on. Confirmed on
    hardware: pixel 0 now matches the rest.
    Required moving the ring's DIN wire from D4 (PA12) to D3 (PB0/TIM3_CH3) -
    PA12 has no timer alternate function on this chip package.
    Known follow-up: BREATHE mode is visibly glitchy under the new transpor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
    [rgb_display.cpp]
2026-07-16 base-station: fix RGB ring flicker on mixed-bit-pattern colors, survives power-cycle
    rgb_pwm_show() reset+reconfigured GPDMA1 channel 4 every 50Hz tick while
    TIM3 free-runs underneath, generating a continuous UPDATE->DMA request
    unlike SPI3/SAI1 (spi_link.cpp/mic_sampler.cpp), whose request lines go
    quiet between transfers. Resetting the channel while that request line
    stays live let a stray request land mid-reset, invisible for uniform
    0x00/0xFF colors but misaligning a slot for any byte with mixed bits -
    the actual cause of the BREATHE glitch (docs/progress3.md ยง7-9).
    Fix keeps the existing full reset+reconfigure (same pattern already
    proven safe for every other GPDMA1 user in this s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
    [rgb_display.cpp]
2026-07-16 base-station: drive local RGB ring from node status, fix WS2812 color skew
    Registry status changes only reached remote satellite nodes over MQTT --
    the base station's own ring had no wiring at all since it has no MQTT
    client to receive its own command back. wire_local_status_led() pushes
    set_rgb over the local Bridge RPC link instead, verified live against a
    real commissioning run.
    That surfaced a second bug: the LED colors were copied from the dashboard's
    screen palette (Tailwind emerald/red), which reads wrong on an uncorrected
    WS2812 -- any non-trivial secondary channel shows up disproportionately
    strongly, so healthy-green looked bluish and fault-red looked pink.
    Switched to near-primar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
    [main.py]
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2026-07-17 feat: generic section-list telemetry frame (SENSOR_TELEMETRY_FRAME_PLAN Phase A)
    Replaces the fixed fuser_frame_header + hardcoded mic/accel blocks with a
    self-describing section-list frame so sensor/bin-combo experiments need no
    frame-parsing edits on either end. One schema file
    (base-station/telemetry_schema.json) generates both the C header and the Python
    constants (gen_telemetry_schema.py), so the two ends can't drift.
    Wire format (LE): [num_sections u8] then per section
    [source_id u8][channel_id u8][data_kind u8][section_len u16][body]; SPECTRUM
    body = fs f32, fft_size u16, bin_count u16, bins f32[]. SCALAR_SET / TIME_SERIES
    kinds defined too. Unknown kinds/channels are skipped by sect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
    [fuser.cpp, spi_link.cpp]
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2026-07-19 base-station: fix perf-stats live-update bug, add GPU perf polling, serialize Bridge access
    run_perf_broadcast_loop had no exception guard, so any single transient
    failure permanently killed the WS push task for the rest of the process's
    life -- GET /perf kept working (separate code path), which is why only a
    page reload ever showed fresh numbers. Now logs-and-continues per tick,
    matching every other poll loop in this codebase (mcu_perf.py had the same
    pattern already).
    Also adds real GPU busy% via a new host-side gpu_bridge.py daemon (mirrors
    spi_bridge.py's root-daemon-plus-socket shape, since the app container
    can't reach the GPU's debugfs counter directly), and a shared bridge_lock.py
    s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
    [gpu_bridge.py, main.py]
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2026-07-20 base-station: add Telegram alerts (untested on hardware)
    Implements docs/DASHBOARD_IDEAS_BACKLOG.md's Telegram alerts item using
    the official arduino:telegram_bot App Lab brick: a dashboard "Connect
    Telegram" deep-link flow (custom /start <token> handler, since the
    brick's own builtin welcome can't see the token), per-subscriber
    fault-only vs fault+warning and node-scope prefs, and fault/warning/
    recovery notifications wired off Registry.on_status_change.
    New alerts/ subpackage (alert_store.py + telegram_alerts.py, the latter
    the only file that touches the real brick, and only inside functions --
    never at import time, so it doesn't require the App Lab container),
    REST routes + a "telegram_s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
    [main.py]
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2026-07-20 base-station: auto-advancing SPI pull protocol + interrupt-driven completion
    Replaces one spi_arm RPC call per chunk (~21-29 round trips/frame, the
    real fps bottleneck once frames grew past a handful of chunks) with
    spi_arm_stream: one RPC call arms a whole frame, and the MCU auto-
    advances chunk-by-chunk on its own thread as each completes. Old
    spi_arm(offset,len) is untouched for tests/spi_link_test.py.
    Also lands two things the auto-advance needed to be reliable:
    - Interrupt-driven DMA completion (GPDMA1 ch3 TC, via a dynamic IRQ)
    instead of polling, so a completed chunk is noticed in microseconds.
    - fuser no longer shares MCU thread priority with spi_link_thread
    (fuser 6->7, mic 7->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
    [app_config.h, sketch.ino, spi_link.cpp]
2026-07-21 base-station: raise accel ODR 1600Hz->12800Hz (Nyquist 800Hz->6400Hz)
    Tried the KX134's 25600Hz hardware ceiling first; confirmed on live
    hardware it stalls the SPI/Bridge telemetry pipeline entirely (frames_ok
    stuck at 0), almost certainly accel_sampler_thread starving Bridge at
    that rate. 12800Hz verified stable (frames_ok climbing, 0 stalls,
    fs=12800 confirmed end-to-end in the telemetry frame).
    [accel_sampler.cpp, app_config.h]
2026-07-21 base-station: fix raw-capture accel display/scalars/freq-axis, sync all 4 channels per frame
    - raw_capture.js: fix accel spectrum/raw-signal charts never rendering
    (frontend never handled the "raw_accel_epoch" batched WS message,
    only single-channel "raw_window")
    - swap per-axis rms_x/kurtosis_x scalars for the project's real 6
    (rms/kurtosis/crest_factor/peak/std/skewness on the combined
    tri-axial vector magnitude), matching fuser.cpp's normal-mode
    compute_scalars() exactly
    - fix frequency-axis calculation (was ignoring the downsample factor
    and DC-bin offset, badly compressing the displayed range) and bump
    live-preview bin-count default 32->512 (native FFT resolution)
    - app_co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
    [app_config.h, fuser.cpp, spi_link.cpp]
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2026-07-22 base-station: add start_desktop_dashboard.sh for MCU-less dashboard testing
    Guards the two arduino.app_utils imports (spi_reader.py, main.py's local
    status LED) with try/except so main.py can run on an ordinary dev machine
    with no App Lab container -- the base_station node simply never appears,
    same as it would with no MCU attached. New start_desktop_dashboard.sh sets
    up the venv, checks for a local MQTT broker, generates synthetic vibration
    CSVs, and brings up the dashboard plus one or more satellite_node_sim.py
    copies so the fleet pipeline can be exercised without real hardware.
    [main.py]
2026-07-22 satellite: import ESP32S3 satellite node firmware, update to section-list telemetry frame
    Ports edgeai-predictive-monitor-unoq/mcu_satellite into this repo as
    satellite/. Its MQTT wire format was stale (a fixed spectrum_fused_payload_header
    wrapped in a [TYPE]-byte envelope, from before the base station moved to the
    generic section-list telemetry frame) -- spectrum_codec/wire_protocol/fuser_task
    now emit the same section-list frame telemetry_frame.py decodes, published raw
    with no envelope on the data topic. gen_telemetry_schema.py now also generates
    satellite/include/frame_codec/telemetry_schema.h so all three sides (base
    station MCU, satellite MCU, MPU parser) derive from one schema. Build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
    [app_config.h, board_pins.h, kx134.cpp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]
2026-07-22 pipeline: derive input_dim per-node from its first frame, stop a bad frame from killing all ingestion
    A node's committed vector length was a hardcoded 512-per-channel table
    (registry.input_dim_for), so any node whose FFT bin count differed from
    that -- including a legitimately reconfigured satellite sim node -- would
    fail bin-count validation on its very first frame. manager.py now derives
    input_dim from what the node's own first frame actually sent
    (_infer_sensor_config_and_dim) and Registry.add() accepts it explicitly,
    falling back to the old fixed table only when no frame is available yet.
    features.py/commissioning.py/inference.py updated to pass that committed
    input_dim through instead o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
    [registry.py]
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2026-07-22 base station: LED matrix fleet-status message, verified live on hardware
    Implements docs/LED_MATRIX_STATUS_PLAN.md: wire_local_matrix_text(registry)
    pushes a rolling H/W/F/O fleet summary to the base station's own 8x13 LED
    matrix on every Registry.on_status_change event (fleet-wide, unlike the
    RGB ring's own-node-only wiring). matrix_status.fleet_status_text() is the
    pure §3 truth-table builder, unit-tested independent of the Bridge call.
    Shorthand words (OK/FLT/WRN/OFF) and zero spaces anywhere in the message
    were tuned live on the physical matrix: every glyph on this firmware's 5x7
    font, including a space, costs a fixed 6-column slot, so a single space
    blanked ~46% of the 13-column-wide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
    [main.py]
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2026-07-22 fault detection: per-axis accel + per-channel scalar features (536-dim), fix dashboard/sim fallout
    Live cycling through bearing/loose/unbalanced fault rigs showed almost no
    separation on the anomaly chart (~4 sigma worst case) because the production
    feature vector was spectrum-only with a single combined accel axis and no
    scalar features. Offline replay against real captures showed per-axis accel
    + per-channel scalars (rms/kurtosis/std/peak/crest_factor/skewness, computed
    separately per accel_x/accel_y/accel_z/mic, never a combined tri-axial
    magnitude) clears the fault threshold at +38.5 sigma worst case.
    Wires that exact config end-to-end for the base station: telemetry_schema
    gains 24 per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
    [app_config.h, fuser.cpp, main.py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]
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2026-07-24 dashboard: capture+label workflow, device identity, and Record drawer redesign
    Adds the capture+label pipeline (pipeline/capture.py, api/capture_controller.py)
    so an operator can save labeled feature-vector batches for Edge Impulse
    training, independent of the existing autoencoder commissioning flow -- wired
    into main.py's frame loop and api/app.py's REST surface (start/stop/save/
    cancel, label listing), with charts.js routing the new "capture"/
    "training_progress" WS broadcasts into the dashboard's existing fleet-state
    handler.
    Each saved capture needs to know which kind of machine it came from, so
    `RegistryEntry.display_name` is renamed to `device_name` and a new
    `device_type` field is ad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
    [main.py, registry.py]
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2026-07-24 ei: wire Edge Impulse project connect + upload (backend)
    Round A of the EI dashboard workflow (docs/EDGE_IMPULSE_DASHBOARD_WORKFLOW_PLAN.md
    S4): pipeline/ei_client.py (stdlib-only REST client: login, create
    project/impulse/NN-config, ingestion upload), pipeline/ei_projects.py
    (device_type -> project/key store, 0600), api/ei_controller.py
    (connect/status/upload orchestration -- standardizes each capture's
    scalar tail against its own node's commissioned baseline before
    upload, closing a train/serve skew gap found during this work), and
    3 new routes in api/app.py (POST /classifier/ei/connect, GET
    /classifier/ei/status, POST /classifier/ei/upload).
    Auth model resolved differently than the plan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
    [main.py]
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2026-07-24 satellite: sync ESP32 firmware to per-axis accel + scalar telemetry contract
    base-station/sketch/fuser.cpp and satellite_node_sim.py moved to per-axis
    accel_x/y/z spectra + a 24-value scalar tail (536-dim model input, commit
    8119e36), but the real ESP32 satellite firmware still sent the old combined
    mic+accel spectrum-only frame -- pipeline/features.py now hard-rejects any
    frame missing a live channel's scalar tile, so a real node couldn't have
    commissioned at all.
    accel_sampler_task/mic_sampler_task now compute per-axis/per-channel
    rms/kurtosis/std/peak/crest_factor/skewness (new dsp/scalar_stats.h, mirrors
    fuser.cpp's compute_scalars() exactly) alongside their spectra.
    frame_codec/spectru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
    [app_config.h]
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2026-07-25 ei: wire fault classifier into live pipeline, fix fetch, round 8 rework
    Bundles the accumulated Edge Impulse dashboard-workflow work:
    - Round 8 (docs/EDGE_IMPULSE_DASHBOARD_WORKFLOW_PLAN.md S8): one-card-
    per-asset-class Classifier tab, Upload always uploads everything and
    wipes the EI project first, pooled per-device-type scalar-tail
    normalization replacing the old per-node commissioning baseline
    (pipeline/ei_scaling.py).
    - Live-account fixes found by exercising a real EI account: the
    impulse's "features" input block needs real per-column axis names,
    not generic ones; build_model()/download_model() were requesting a
    bare non-zip .tflite (type param conflated with engine), whi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
    [main.py, registry.py]
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2026-07-25 base-station: auto-detect MQTT broker instead of patch+restart hack
    main.py now defaults --mqtt-host to its own docker-bridge gateway IP
    (reads /proc/net/route itself, mirroring what start_sim_node.sh used to
    do externally via adb) so the app self-configures MQTT on every boot --
    no more sed-patching the on-device main.py and restarting the container
    just to point it at a broker.
    Made this safe by switching MqttSubscriber/MqttPublisher from paho's
    blocking connect() to connect_async(): wire_status_led_publishing()
    builds an MqttPublisher synchronously before the app starts, so with a
    guessed address and no broker there yet, the old blocking connect()
    would have crashed the whole app on ever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
    [main.py]
2026-07-25 dashboard: fix per-frame registry I/O and MQTT thread blocking causing freezes/stalls
    registry.py: touch_last_seen/record_anomaly_score/record_classification were
    doing a synchronous full-registry.json rewrite on every single scored frame,
    while holding the same per-node lock REST mutations (pause/rename/commission)
    block on. Any storage hiccup turned into a total dashboard freeze -- buttons
    unresponsive, charts stuck, node eventually reading offline once last_seen
    stopped advancing. Confirmed by 13 orphaned zero-byte .registry-*.tmp files
    on-device spanning over a week, evidence of writes getting killed mid-flight
    repeatedly. None of these three fields need disk durability (all
    per-frame-re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
    [registry.py]
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2026-07-29 dashboard: implement + live-verify base station WiFi onboarding
    Builds docs/WIFI_ONBOARDING_PLAN.md §1: a root-owned host/wifi_bridge.py
    daemon (systemd, mirrors the SPI/GPU bridges) drives nmcli since the app
    container can't touch wlan0 directly, falling back to an open
    EPM-BaseStation hotspot whenever the board isn't joined to a real
    network. The dashboard's previously-empty Network tab now hosts the
    status view + join form, backed by new GET/POST /network/wifi/* routes.
    Live-verified end-to-end on real hardware: killed the board's real WiFi,
    watched the hotspot fallback come up, joined it from a phone, and
    rejoined the real network through the actual form. That test surfaced
    and fixed t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
    [main.py, wifi_bridge.py]
2026-07-29 dashboard: WiFi onboarding captive-portal auto-open, network scan, messaging fixes
    Round 2: adds the actual captive-portal auto-open behavior (dnsmasq
    wildcard DNS + a port-80 redirect in wifi_bridge.py, plus an app.js
    ?tab= deep link) so joining the onboarding hotspot pops a login page
    automatically like airport WiFi, a network scan/pick list alongside
    manual entry, and clearer connect success/failure messaging.
    Round 3: live-tested on a real phone. Fixed scan forcing a slow (~7s)
    rescan on every call and silently treating any failure the same as an
    empty result -- switched to nmcli's own cache-freshness judgment and
    threaded a distinct error field through so a real failure is
    distinguisha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
    [wifi_bridge.py]
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2026-07-30 base-station: enable Telegram alerts brick, drop manual bot-username step
    Declares arduino:telegram_bot in app.yaml (previously reverted -- see
    1b2cbce) now that a concurrent device build isn't at risk. Also removes
    the TELEGRAM_BOT_USERNAME env var requirement entirely: the bot's
    @username is now resolved automatically via Telegram's own getMe API
    using the already-configured TELEGRAM_BOT_TOKEN, so App Lab's brick
    secret is the only manual config step left. Live-verified against a
    real Telegram bot and account.
    [main.py]
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2026-07-30 motor-driver: rename from demo/, support 3 motors, move ramp to host
    Renames demo/ to motor-driver/ (matching base-station/satellite naming) and
    flattens it to the same layout. Adds a third motor (X/Y/Z) and drops all
    on-device ramp/accel/governor logic from the firmware: it now applies
    whatever RPM it's told immediately via setSpeed()/runSpeed(), and all
    ramping lives in dashboard.html and run_demo.py instead, since re-flashing
    this Uno needs a slow WSL upload/detach/reconnect round-trip.
    Also fixes two bugs found live on real hardware:
    - Stopping a motor only sent 'd' and reset dashboard-local state; the
    firmware still held the motor's last commanded RPM, so starting any other
    motor (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
    [main.cpp]
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

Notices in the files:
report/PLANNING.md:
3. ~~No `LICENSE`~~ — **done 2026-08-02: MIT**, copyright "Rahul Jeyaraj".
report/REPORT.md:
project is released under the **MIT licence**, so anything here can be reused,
